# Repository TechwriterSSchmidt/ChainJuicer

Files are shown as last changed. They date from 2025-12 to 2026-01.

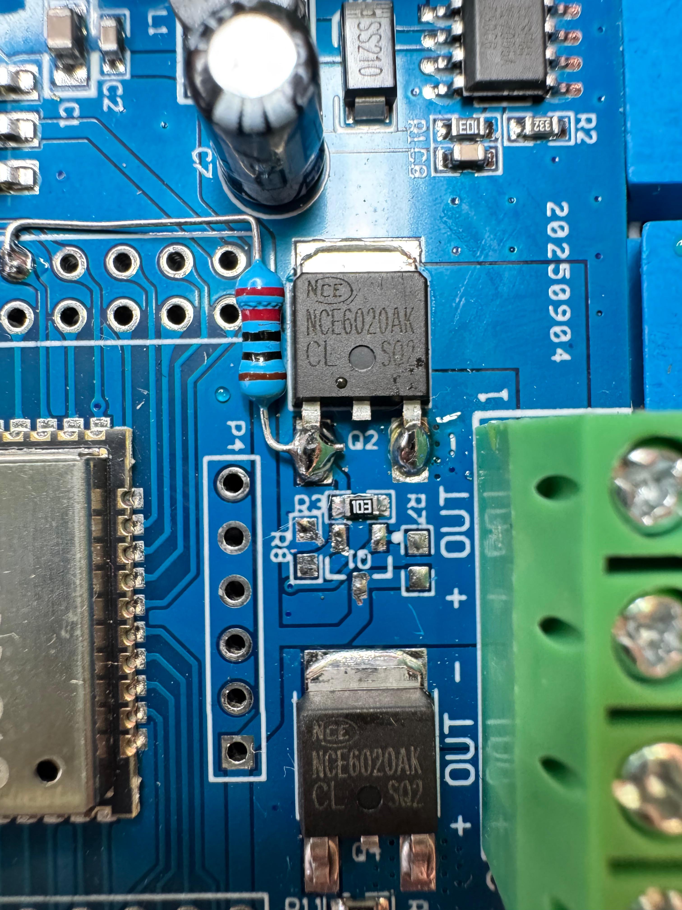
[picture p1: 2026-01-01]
pictures/Top view showing (or NOT showing) the desoldered transistor, R7 and R8.jpeg

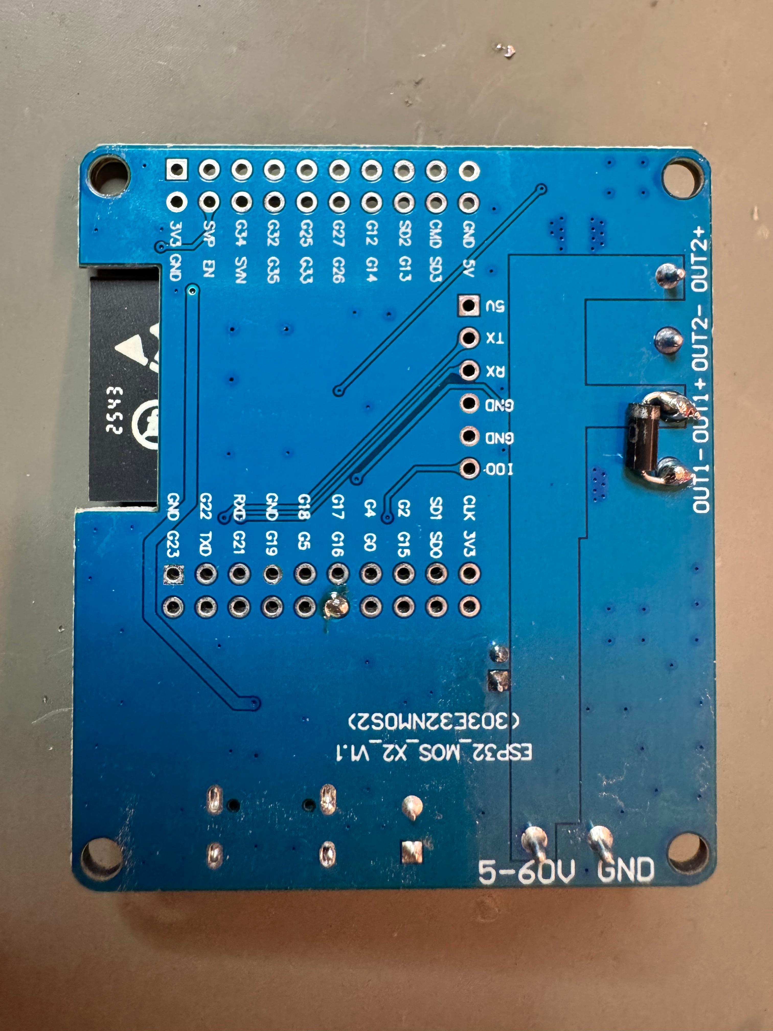
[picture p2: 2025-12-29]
pictures/Rear view showing the free-wheeling diode for the solenoid pump.jpeg

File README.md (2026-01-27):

# 🍋 Chain Juicer v2.0.0 (ESP32)

**The Swiss Army Knife for your Motorcycle Chain.**

An ESP32-based multi-tool featuring GPS-controlled chain lubrication, a Aux Power Manager for accessories, and an automated Heated Grips Controller. It combines intelligent maintenance with modern convenience and safety features like IMU-based crash detection.

**Easy to Build:** Designed around a widely available standard ESP32 Relay Board (LCTECH), this project requires **no custom PCB** and minimal soldering skills. It's the perfect entry point for DIY motorcycle electronics.

**Easy to Install:** No coding skills required! Use the [Web Installer](https://TechwriterSSchmidt.github.io/ChainJuicer/) to flash your ESP32 directly from the browser. Future updates can be done wirelessly via OTA (Over-The-Air) using the [latest firmware file](https://TechwriterSSchmidt.github.io/ChainJuicer/firmware.bin).

> **Note:** Version 2.0.0 introduces a new core architecture. For optimal stability and to prevent boot loops, please follow the **Recommended Pin Layout** below when building new hardware.

## Support my projects

If you like this project, consider a tip. Your tip motivates me to continue developing useful stuff for the DIY community. Thank you very much for your support!



## Recommended Pin Layout (Hardware v2.0)

For the most stable operation (avoiding "Boot Loops" and conflicts with internal ESP32 Strapping Pins), use the following connection scheme for new builds. 

| Component | ESP32 Pin (GPIO) | Notes |
| :--- | :--- | :--- |
| **PUMP (MOSFET)** | **GPIO 26** | Safe Output |
| **LED (WS2812B)** | **GPIO 32** | Standard |
| **BUTTON** | **GPIO 0** | Use Boot Button or external btn to GND |
| **TEMP (DS18B20)** | **GPIO 4** | **Important:** Requires 4.7kΩ Pull-Up Resistor. Do not use GPIO 2! |
| **GPS RX** | **GPIO 16 (RX2)** | Connect to GPS TX |
| **GPS TX** | **GPIO 27** | Connect to GPS RX |
| **IMU (SDA)** | **GPIO 21** | Standard Hardware I2C |
| **IMU (SCL)** | **GPIO 22** | Standard Hardware I2C |
| **SD Card (CS)** | **GPIO 5** | VSPI CS |
| **SD Card (CLK)** | **GPIO 18** | VSPI CLK |
| **SD Card (MISO)** | **GPIO 19** | VSPI MISO |
| **SD Card (MOSI)** | **GPIO 23** | VSPI MOSI |

> **Warning:** Avoid using **GPIO 12**, as it determines the flash voltage during boot (High = Boot Loop). Avoid **GPIO 2** for sensors with pull-ups for the same reason.

## Table of Contents
* [Features](#features)
* [Optional IMU Features](#optional-imu-features)
* [Optional SD Card Logging](#optional-sd-card-logging)
* [Hardware & Functionality Matrix](#hardware--functionality-matrix)
* [Automatic Temperature Compensation](#automatic-temperature-compensation)
* [Aux Port Manager](#aux-port-manager-gpio-17)
* [Data Logging (SPI Flash)](#data-logging-spi-flash)
* [Hardware](#hardware)
* [Operation](#operation)
* [Web Interface](#web-interface)
* [License](#license)
* [Installation](#installation)
* [BOM & Costs](#bom--costs-approx-2025)
* [Release Notes](RELEASE_NOTES.md)

## Features

| Feature | Description | Details |
| :--- | :--- | :--- |
| **Speed-Dependent Oiling** | 5 configurable speed ranges with individual intervals. | Intervals down to **0.1 km**. Pre-configured "Swiss Alpine Profile" (Base 5km, optimized for passes & highways). Default: 2 pulses/event. |
| **Smart Smoothing** | Linear interpolation & low-pass filter. | Avoids harsh jumps in lubrication intervals. |
| **Drift Filter** | Ignores GPS multipath reflections. | Prevents "ghost mileage" indoors/tunnels (HDOP > 5.0 or < 5 Sats). |
| **Safety Cutoff** | Hard limit for pump runtime. | Max 30s continuous run to prevent hardware damage. |
| **Start Delay** | Distance driven before first oiling. | Default **250 m**. Keeps garage floor clean. |
| **GPS Precision** | Exact distance measurement. | Uses TinyGPS++ library. |
| **Rain Mode** | Doubles oil amount in wet conditions. | **Button:** 1x Click. **Auto-Off:** 30 min or restart. LED: Blue Static. |
| **Chain Flush Mode** | Intensive oiling for cleaning/re-lubing. | **Button:** 4x Click. **Action:** Time-based (Configurable). LED: Cyan Blink (pulses while riding). |
| **Offroad Mode** | Time-based oiling for slow offroad riding. | **Button:** 3x Click. **Action:** Time-based (Pulses configurable). LED: Magenta Blink (pulses while riding). |
| **Emergency Mode** | Simulates speed if GPS fails. | **Auto:** After 3 min no signal (50 km/h sim). **Forced:** Manual activation. LED: Red Pulsing. |
| **WiFi & WebUI** | Configuration via Smartphone. | **Activation:** 5x Click. **Features:** OTA Update, LED config, Stats, Test functions. |
| **Night Mode** | Auto-dimming of LED. | **Default:** ON (20:00-06:00). Brightness: 5% (Dim) / 25% (Event). |
| **Bleeding Mode** | Continuous pumping for maintenance. | **WebUI:** "Start Bleeding Mode" Button. Fills oil line (25s). **Additive:** Trigger again to extend (max 75s). LED: Yellow Fast Blink. |
| **Tank Monitor** | Virtual oil level tracking. | **Default:** ON. Warns (Orange Fast Blink) when low (< Warning%). Red/Yellow Alt when empty. |
| **Aux Port Manager** | Smart control for accessories. | **Aux Power:** Auto-ON after boot (Delay). **Heated Grips:** Auto-PWM based on Speed/Temp/Rain. **Toggle:** Hold > 2s. |
| **Web Console** | Debugging without USB. | View live logs (GPS, Oiler, System) via WiFi on `/console`. |
| **Advanced Stats** | Usage analysis. | Usage % per speed range, total juice counts, odometer. |
| **Auto-Save** | Persistent storage. | Saves settings & odometer to NVS at standstill (< 7 km/h). |
| **Factory Reset** | Reset to defaults. | **WebUI:** Maintenance Page. |

## Optional IMU Features

By adding a **BNO085** (or BNO080) 9-Axis IMU, the system gains "Intelligence" and advanced safety features. The system automatically detects if the sensor is connected.

| Feature | Description | Benefit |
| :--- | :--- | :--- |
| **Garage Guard** | Detects if the bike is **Stationary** (Stability Check). | Prevents accidental oiling in the garage, even if the motor is running or GPS drifts. (5s stability check) |
| **Crash Detection** | Detects tip-overs (> 70° lean) or accidents. | Immediate safety cutoff for the pump. **Requires restart to reset.** |
| **Smart Stop** | Detects standstill via accelerometer before GPS reacts. | More precise oiling stops at traffic lights. **Visuals:** LED pulses Green (OK) or Red (Empty) when stopped. |
| **Telemetry Logger** | Records max lean angles (L/R), max acceleration, and braking G-forces. | Fun stats for the web interface ("How deep was I in that corner?"). |
| **Dynamic Intervals** | Analyzes riding style (Cruising vs. Racing). | Reduces oiling intervals during aggressive riding (high load on chain). |

*   **Calibration:** A dedicated Web Interface page allows zeroing the sensor. Includes a 5-second countdown and 3-second averaging for easy solo calibration.
*   **Logging:** All IMU data will be logged to the SD card (if active) for analysis.

## Optional SD Card Logging

For advanced users and data analysis, you can connect a standard **MicroSD Card Module** (SPI). The system automatically detects the card at boot and starts logging telemetry data.

*   **File Format:** CSV (Comma Separated Values)
*   **Interval:** 1 Second
*   **Files:** `log_X.csv` (Increments automatically)

### Wiring (VSPI Default)

| Pin | ESP32 GPIO |
| :--- | :--- |
| **CS** | GPIO 5 |
| **MOSI** | GPIO 23 |
| **MISO** | GPIO 19 |
| **CLK** | GPIO 18 |
| **VCC** | 5V |
| **GND** | GND |

### Logged Data

| Column | Description |
| :--- | :--- |
| **Type** | Event type (DATA = Periodic, EVENT = System Event) |
| **Time_ms** | System uptime in milliseconds |
| **Speed_GPS** | Raw GPS speed (km/h) |
| **Speed_Smooth** | Smoothed speed used for calculation (km/h) |
| **Odo_Total** | Total odometer reading (km) |
| **Dist_Accum** | Distance accumulated towards next oiling (km) |
| **Target_Int** | Current target interval (km) |
| **Pump_State** | 1 = Pump running, 0 = Idle |
| **Rain_Mode** | 1 = Active, 0 = Inactive |
| **Temp_C** | Current temperature (°C) |
| **Sats** | Number of satellites |
| **HDOP** | GPS Precision (Lower is better) |
| **Message** | System messages or debug info |
| **Flush_Mode** | 1 = Active, 0 = Inactive |

## Hardware & Functionality Matrix

This table shows which features are available depending on the connected hardware components.

| Feature | Basic Setup | + Temp Sensor | + IMU (MPU6050) | + SD Card |
| :--- | :---: | :---: | :---: | :---: |
| **Speed-Dependent Oiling** | ✅ | ✅ | ✅ | ✅ |
| **Rain Mode** | ✅ | ✅ | ✅ | ✅ |
| **Chain Flush Mode** | ✅ | ✅ | ✅ | ✅ |
| **Cross-Country Mode** | ✅ | ✅ | ✅ | ✅ |
| **Emergency Mode** | ✅ | ✅ | ✅ | ✅ |
| **Night Mode** | ✅ | ✅ | ✅ | ✅ |
| **Tank Monitor** | ✅ | ✅ | ✅ | ✅ |
| **Temp. Compensation** | ❌ | ✅ | ✅ | ✅ |
| **Turn Safety (Cornering)** | ❌ | ❌ | ✅ | ✅ |
| **Crash Detection** | ❌ | ❌ | ✅ | ✅ |
| **Garage Guard** | ❌ | ❌ | ✅ | ✅ |
| **Smart Stop** | ❌ | ❌ | ✅ | ✅ |
| **Aux Port: Aux Power** | ✅ | ✅ | ✅ | ✅ |
| **Aux Port: Heated Grips** | ❌ | ✅ | ✅ | ✅ |
| **Data Logging** | ❌ | ❌ | ❌ | ✅ |

*   **Basic Setup:** ESP32, GPS Module, Pump, Button, LED.
*   **Temp Sensor:** DS18B20 (OneWire).
*   **IMU:** BNO085 (I2C).
*   **SD Card / Flash:** SPI Flash / MicroSD for Logging.

## Automatic Temperature Compensation

This system uses a **DS18B20** temperature sensor to adjust the pump mechanics based on the viscosity of the oil.

**Why?**
Oil becomes thick like syrup in winter and thin like water in summer. Without compensation, the pump might fail to move cold oil or squirt too much hot oil.

**New Simplified Logic (Arrhenius):**
Instead of complex tables, the system uses the Arrhenius equation to model oil viscosity changes.

*   **Reference:** You set the optimal Pulse and Pause duration for **25°C** (Normal Temperature).
    *   *Recommendation:* Use a long pause (~2000ms) and adjust the pulse width. This ensures the pump always has enough time to refill, even with thick, cold oil.
*   **Oil Profile:** Select your oil type (Thin, Normal, Thick).
*   **Calculation:** The ESP32 automatically calculates the required energy for any temperature.
*   **Safety Limits:**
    *   **Minimum Pulse:** The system enforces a hard limit of **50ms** for the pulse duration to ensure the solenoid always moves, preventing "stuck" states at high temperatures.
*   **Update Interval:** Temperature is measured every 1 minute to ensure stable operation.

**Configuration:**
*   **Web Interface:** Simply enter your 25°C values and select the oil type.
*   **Sensor Detection:** If no sensor is connected, the system defaults to 25°C.

**Wiring:**
*   **VCC:** Board dependent (e.g. 5V-12V for Wide Range boards, or 3.3V/5V for standard)
*   **GND:** GND
*   **Data:** GPIO 4 - Requires 4.7kΩ Pull-Up Resistor to VCC.

## IMU Features (BNO085)

If an IMU is connected, the system enables advanced safety and convenience features:

*   **Turn Safety:** Prevents oiling while significant cornering.
    *   **Logic:** Oiling is paused if the bike leans > 20° towards the **tire side** (unsafe zone). Leaning towards the chain side is considered safe (oil drops on chain, not tire).
*   **Crash Detection:** Stops the pump immediately if the lean angle exceeds 70° (bike on ground).
*   **Garage Guard:** Detects if the bike is on the side stand or center stand and prevents oiling (even if GPS drifts).
*   **Smart Stop:** Uses accelerometer data to detect standstill faster than GPS.

## Aux Port Manager (GPIO 17)

The system features a versatile Auxiliary Output (MOSFET/Relay driver) that can be configured for two main purposes:

### 1. Aux Power (Switched Live)
Turns on your accessories (Navigation, USB, Lights) automatically when the ignition is ON.
*   **Logic:** Activates the output after a configurable delay when the ESP boots.
*   **Start Delay:** Configurable delay (default 15s) to protect the battery during engine cranking.
*   **Benefit:** No need to tap into the bike's wiring harness or ignition switch. Connect directly to the battery via the Chain Juicer.

### 2. Automated Heated Grips
Advanced PWM control for heated grips, far superior to simple "Low/High" switches.
*   **Hardware Recommendation:** [Coolride Heating Cartridges](https://www.coolride.de/Neue-Heizpatronen-Paar-einzeln-ohne-Schalter) (52W).
*   **Base Level:** Set your preferred minimum heat. **Default: 25%**.
*   **Speed Compensation:** Increases heat as you ride faster (Wind chill factor). **Default: 0.5x** (Medium).
*   **Temp Compensation:** Increases heat as it gets colder (requires Temp Sensor). **Default: 2.0x** (High).
*   **Start Temp:** Configurable threshold (**Default: 20°C**) below which the grips start working.
*   **Temp Offset:** Adjusts the sensor reading if placed near heat sources (e.g. engine).
*   **Rain Boost:** Automatically adds extra heat when Rain Mode is active. **Default: +10%**.
*   **Startup Boost:** Heats up quickly (**Default: 100% for 75s**) when you start the ride.
*   **Start Delay:** Configurable delay (**Default: 15s**) after boot before grips turn on to protect the battery.
*   **Reaction Speed:** Configurable smoothing (Slow/Medium/Fast) to determine how quickly the heat adjusts to speed changes.
    *   **Slow (Default):** ~10s smoothing. Very comfortable, filters out traffic lights.
    *   **Medium:** ~5s smoothing. Balanced.
    *   **Fast:** ~1s smoothing. Sporty response.

**Configuration:**
All parameters (Base %, Speed Factor, Temp Factor, Boosts, Delays, Reaction) are fully configurable via the new "Aux Config" web page.
**Default Mode:** The Aux Port is **OFF** by default and must be enabled in the Web Interface.

## Data Logging (SPI Flash)

For vibration-heavy environments or integrated builds, the system supports SPI Flash memory (simulated as SD card) for durable data logging.

**Recommended Hardware:**
*   **Adafruit SPI Flash SD Socket Adapter** (Product ID: 4899)
    *   *Why?* It acts like an SD card but is a soldered chip. Completely vibration-proof.
    *   *Capacity:* 512 MB (plenty for years of logs).

**Storage Capacity (512 MB Example):**
The system logs GPS tracks, speed, and events to `gps_log.csv`.

| Metric | Value |
| :--- | :--- |
| **Log Format** | CSV (Timestamp, Lat, Lon, Speed, Satellites, Alt) |
| **Data Rate** | 1 log entry per second (approx. 60 bytes) |
| **Storage per Hour** | ~216 KB |
| **Storage per 1000km** | ~3.6 MB (Avg. 60km/h) |
| **Total Capacity** | **> 140,000 km** of riding history |

**Data Retrieval:**
Since the chip is soldered, you cannot remove it.
*   **Web Download:** Use the "Maintenance" page in the Web Interface to download the full log file as `gps_log.csv`.

## Hardware

*   **MCU:** [LCTECH ESP32 Relay X1](http://www.chinalctech.com/cpzx/Programmer/Relay_Module/866.html).
    *   *Specs:* ESP32-WROOM-32E, Wide Range Input (7-30V), 2x Onboard MOSFET (**NCE6020AK**).
*   **GPS:** ATGM336H or NEO-6M (UART, 9600 Baud)
*   **Pump:** [12V Dosing Pump](https://de.aliexpress.com/item/1005010375479436.html).
    *   *Durability:* Tested with 2 pumps, each > 100,000 strokes without failure.
    *   *Tip:* Use my [Smart Pump Calibrator](https://github.com/TechwriterSSchmidt/Smart-Pump-Calibrator) to find the perfect settings for your pump.
*   **Temp Sensor:** DS18B20 (Waterproof)
*   **IMU (Optional):** BNO085 (or BNO080) for lean angle detection and standstill logic.
*   **LED:** WS2812B (NeoPixel) for status indication
*   **Button:** Normally Open against GND (Input Pullup)

### Pin Assignment (Current Config)

| Component | ESP32 Pin | Description |
| :--- | :--- | :--- |
| **Pump** | GPIO 26 | MOSFET Gate (Direct Drive) |
| **GPS RX** | GPIO 16 | Connected to GPS TX |
| **GPS TX** | GPIO 27 | Connected to GPS RX |
| **Button** | GPIO 0 | Switched against GND |
| **Boot Button** | GPIO 0 | Onboard Button (Parallel function) |
| **LED** | GPIO 32 | WS2812B Data In |
| **Temp Sensor** | GPIO 4 | DS18B20 Data (with 4k7 resistor between VCC and Data!) |
| **IMU SDA** | GPIO 21 | I2C Data |
| **IMU SCL** | GPIO 22 | I2C Clock |

*(Configurable in `include/config.h`)*

### MOSFET Wiring (Direct Drive)

To prevent the pump from triggering briefly during boot, desolder the little driver transistor of one output MOSFET (NCE6020AK) and connect the Gate of the MOSFET via a 220 Ohm resistor directly to the GPIO of the ESP. Add a Pull-Down resistor to stabilize the MOSFET. This modification may not be necessary for the Aux Port - your choice!

**Recommended Fuses:**
*   **Main Fuse (Battery):** 15A (Blue) - Protects the entire system.
*   **Aux Circuit (Grips):** 7.5A (Brown) - Protects the heated grips wiring (Load ~5.2A).
*   **Pump Circuit:** 5A (Tan) - Protects the pump and its MOSFET (Load ~4A Peak).

**Important:** The 220Ω series resistor and 10kΩ Pull-Down resistor are **mandatory** to prevent the pump from running uncontrollably during the ESP32 boot sequence.

```ascii
ESP32 GPIO (the one that switches the MOSFET
)  ----[ 200R ]----+-----> MOSFET Gate
                               |
                              [existing SMD pull-down resistor with 10k]
                               |
                              GND
```

*   **200R (Series):** Protects the ESP32 pin from current spikes (Gate capacitance).
*   **10k (Pull-Down):** Keeps the Gate at GND (0V) while the ESP32 is booting.

## Operation

### Button Functions

| Action | Duration | Condition | Function |
| :--- | :--- | :--- | :--- |
| **1x Click** | < 1s | Not in Emergency Mode | **Rain Mode** On/Off (LED: Blue). **Note:** Toggles with 600ms delay. |
| **3x Click** | < 2s | Always | **Offroad Mode** On/Off (LED: Magenta Blink). Time based oiling. |
| **4x Click** | < 2s | Always | **Chain Flush Mode** On/Off (LED: Cyan Blink). Time-based (Configurable). |
| **5x Click** | < 2s | Always | Activate **WiFi & Web Interface** (LED: White pulsing). |
| **Hold** | > 2s | Always | **Aux Port / Grip Heating** Manual Toggle (Override). |
| **Hold at Boot** | > 10s | During Power-On | **Factory Reset** (LED: Yellow -> Red fast blink) |

### Mode Hierarchy & Interactions

If multiple modes are active simultaneously, the system follows this priority logic:

| Priority | Mode | LED Indication | Interaction Notes |
| :--- | :--- | :--- | :--- |
| **1 (Highest)** | **Chain Flush** | **Cyan Blink** | Runs in parallel with Offroad Mode. Requires Speed > 7 km/h. |
| **2** | **Offroad** | **Magenta Blink** | Runs in parallel with Flush Mode. GPS speed is ignored; if IMU is present, oiling happens only when motion is detected. |
| **3** | **Emergency** | **Red Pulsing** | Active if GPS is lost. **Disables Rain Mode.** Note: Flush/Offroad will NOT oil because GPS speed is 0. |
| **4 (Lowest)** | **Rain** | **Blue** | Disabled by Emergency Mode. |

### LED Status Codes

| Color / Pattern | LED 1 (Main System) | LED 2 (Aux Port) |
| :--- | :--- | :--- |
| **Green** | Normal Operation (GPS Fix) | Aux Power: **ON** (12V Active) |
| **Blue** | Rain Mode Active | Heated Grips: **Level 1** (Low) |
| **Yellow** | Oiling Event (Breathing) / Bleeding Mode (Fast Blink) | Heated Grips: **Level 2** (Medium) |
| **Orange** | Tank Warning (2x Blink; pulses while riding) | Heated Grips: **Level 3** (High) |
| **Red** | Emergency Mode (Pulsing) | Heated Grips: **Level 4** (Max) |
| **Cycle** | - | Heated Grips: **Boost** (Blue->Red) |
| **Magenta** | No GPS (Solid) / Offroad (Blink; pulses while riding) | - |
| **Cyan** | Flush (Blink; pulses while riding) | - |
| **White** | WiFi Config Mode (Pulse) | - |
| **Red/Yellow** | Tank Empty (Alternating) | - |
| **Off** | - | Aux Port: **OFF** |

**Safety Note:** While riding, the system uses only **steady** or **pulsing** LED patterns to reduce distraction. Hard blinking is limited to standstill, maintenance, or warnings.

## Web Interface

Connect to the WiFi network (Default SSID: `ChainJuicer`, no password) after activating it. Open `192.168.4.1` in your browser.

**Adjustable Parameters:**
*   **Intervals:** Distance and pump pulses for 5 speed ranges.
*   **Modes:** Rain Mode, Emergency Mode (Force), Night Mode (Times & Brightness).
*   **LED:** Brightness for Day and Night (in %).
*   **Statistics:**
    *   **Usage %:** Driving profile analysis to optimize intervals.
    *   **Juices:** Counter for oilings per range.
    *   **Reset:** Reset stats or refill tank.

**Screenshots:** Check out the [web-ui examples](web-ui%20screenshots/)  folder to see what the interface looks like.

## Usage Scenarios & LED Status

The system uses two LEDs to communicate its status.
*   **LED 1 (Main):** System Status, Oiling, Warnings.
*   **LED 2 (Aux):** Status of the Auxiliary Port (Heated Grips / Aux Power).

| Scenario | Trigger / Action | LED 1 (Main) | LED 2 (Aux) | System Behavior |
| :--- | :--- | :--- | :--- | :--- |
| **Normal Ride** | GPS Fix, Speed > 7 km/h | **Green** | *State dependent* | System oils automatically based on speed and configured distance intervals. |
| **Oiling Event** | Distance reached | **Yellow Breathing** | *State dependent* | Pump releases oil pulse. |
| **Tunnel / Signal Loss** | No GPS signal > 3 min | **Red Pulsing** | *State dependent* | Enters **Auto Emergency Mode**. Assumes 50 km/h for oiling. Returns to Green when GPS is back. |
| **Rain Ride** | 1x Click | **Blue** | *State dependent* | **Rain Mode** active. Oiling amount is doubled (or interval halved). Auto-off after 30 min or restart. |
| **Aux Port: Manual Toggle** | Hold > 2s | *State dependent* | **Off / On** | Manually toggles the Aux Port (Override). |
| **Offroad / Enduro** | 3x Click | **Magenta Blink** | *State dependent* | **Offroad Mode** active. Oils based on time. If IMU is present, oiling happens only when motion is detected (GPS speed is ignored). |
| **Dust / Flushing** | 4x Click | **Cyan Blink** | *State dependent* | **Chain Flush Mode** active. Oils based on time (e.g. every 60s). Good for flushing dust or after cleaning. |
| **Configuration** | 5x Click | **White Pulse** | *State dependent* | Activates WiFi AP `ChainJuicer`. Open `192.168.4.1` to config. |
| **Tank Empty** | Reserve reached | **Red/Yellow Alternating** | *State dependent* | **Tank Empty**. Refill tank and reset counter via Web Interface. |
| **Aux Port: Aux Power** | Ignition ON (Delay) | *State dependent* | **Green** | Aux Port is ON (12V). Powers accessories like Dashcam/Navi. |
| **Aux Port: Heated Grips** | Auto-Control | *State dependent* | **Blue &rarr; Red** | **Blue:** Low Heat<br>**Yellow:** Medium Heat<br>**Orange:** High Heat<br>**Red:** Max Heat |
| **Hardware Debug** | Pump runs at boot | **Check Wiring!** | **Check Wiring!** | Ensure 10k Pull-Down resistor is installed between Gate and GND. |

## Technical Details

*   **Non-Blocking:** Pump control is asynchronous.
*   **Adaptive Smoothing:** Combination of Lookup Table and Low-Pass Filter.
*   **Smart Oiling (Hysteresis):** Start threshold at **95%**, trigger at **100%** (95% + 5% = 100%).
*   **Auto-Save:** The odometer is saved intelligently (at standstill < 7 km/h, but max. every 2 minutes).
*   **Timezone:** Automatic calculation of Central European Time (CET/CEST).

## Installation

### Option A: Web Installer (Recommended)
Flash the firmware directly from your browser (Chrome/Edge) without installing any software.
**[Open Web Installer](https://TechwriterSSchmidt.github.io/ChainJuicer/)**

### Option B: PlatformIO (For Developers)

**Important:** The recommended ESP32-32E board does **not** have a built-in USB-to-Serial converter. You need an external **USB-to-UART Adapter** (e.g., CP2102, CH340) to flash the initial firmware once. For updates, you can use the OTA page to upload new firmware via the webinterface.

*   **Connections:** TX->RX, RX->TX, GND->GND, 3.3V->3.3V (or 5V->5V).
*   **Boot Mode:** You might need to bridge GPIO0 to GND during power-up to enter bootloader mode.

1.  Clone or download the repository.
2.  Open in VS Code with installed **PlatformIO** Extension.
3.  Adjust Upload Port in `platformio.ini` if necessary.
4.  Compile and upload project (`Upload`).
5.  File system is not necessary (Data is saved in NVS/Preferences).

## BOM & Costs (approx. 2025)

The total project cost is very low compared to commercial alternatives (~150€+).

| Component | Description | Link (Example) | Approx. Price |
| :--- | :--- | :--- | :--- |
| **ESP32 Board** | LCTECH Relay X1 (NCE6020AK) | [Manufacturer](http://www.chinalctech.com/cpzx/Programmer/Relay_Module/866.html) | ~ 6.00 € |
| **GPS Module** | ATGM336H (Small & Fast) | [AliExpress](https://de.aliexpress.com/item/1005007759554488.html) | ~ 4.50 € |
| **Dosing Pump** | 12V Pulse Pump | [AliExpress](https://de.aliexpress.com/item/1005010375479436.html) | ~ 12.00 € |
| **Oil Tank** | 120cc RC Tank | [AliExpress](https://de.aliexpress.com/item/1588019770.html) | ~ 4.00 € |
| **Dosing Needle** | 14G Needle (100mm) | [AliExpress](https://de.aliexpress.com/item/1005010382140407.html) | ~ 2.00 € |
| **Luer Lock Adapter** | Adapter for Needle | [AliExpress](https://de.aliexpress.com/item/1005003777344843.html) | ~ 1.00 € |
| **TPU Hose** | 2m Oil/Fuel Line | [AliExpress](https://de.aliexpress.com/item/1005005390968147.html) | ~ 3.00 € |
| **Button** | Waterproof Button | [AliExpress](https://de.aliexpress.com/item/1005009185830140.html) | ~ 0.70 € |
| **LED** | WS2812B (Code supports up to 2x) | Generic | ~ 1.00 € |
| **Fuses** | KFZ-Flachsicherungen (15A, 7.5A, 5A) | Generic | ~ 2.00 € |
| **Small Parts** | Automotive Connectors (2x 2pin, 1x 4pin), Wires | Generic | ~ 13.00 € |
| **Housing** | 3D Printed (PETG/ASA) | DIY | ~ 2.00 € |
| **Flasher** | USB-to-UART Adapter (CP2102/CH340) | Generic | ~ 3.00 € |
| **Total (Basic)** | | | **~ 52.50 €** |
| | | | |
| **Temp Sensor (Optional)** | DS18B20 (Waterproof) | [AliExpress](https://de.aliexpress.com/item/1005006090368473.html) | ~ 1.50 € |
| **IMU (Optional)** | BNO085 (9-Axis) | [AliExpress](https://de.aliexpress.com/item/1005009898088463.html) | ~ 15.00 € |
| **SD Card (Optional)** | MicroSD SPI Module | [AliExpress](https://de.aliexpress.com/item/1005005302035188.html) | ~ 1.00 € |
| **Total (Full)** | | | **~ 70.00 €** |

*Note: Prices vary by shipping location and seller.*

### Hardware Notes
*   **LED:** The code is configured for **2x WS2812B LEDs**. You can use one for the Chain Juicer status display in the cockpit and a second one (optional) for the Aux Port (Grip Heating or Aux Power).
*   **LCTECH Board Modification (Critical):** If you are using the LCTECH Relay Board with the NCE6020AK MOSFET and J3Y driver circuit, you should modify the switching circuit of the pump (only the pump circuit!) to prevent the pump from triggering briefly during boot as follows:
    1.  **Remove:** Transistor `J3Y` (S8050) and Resistors `R8` & `R7`.
    2.  **Keep:** Resistor `R3` (10k Pull-Down).
    3.  **Add:** A **220 Ohm** resistor between GPIO 16 and the Gate of the MOSFET.
    *   *See `Docs/SCHEMATIC.txt` for details.*

## Disclaimer & Safety

**READ CAREFULLY BEFORE BUILDING OR USING THIS SYSTEM!**

*   **DIY Project:** This is a Do-It-Yourself project. You are solely responsible for the assembly, installation, and operation of the system.
*   **No Liability:** The author accepts **no liability** for any damage to your motorcycle, property, or person, nor for any accidents caused by the use or failure of this system.
*   **Oil on Tires:** Chain oilers involve liquids near moving parts. **Oil on the tire significantly reduces traction and can lead to crashes.**
    *   Ensure the dosing needle is positioned correctly so oil drips ONLY on the chain/sprocket, never on the tire or brake disc.
    *   Regularly check the system for leaks.
    *   **IMMEDIATELY clean any oil off the tire** if a spill occurs. Do not ride with oil on your tires.
*   **Road Safety:** Do not operate the configuration interface while riding. Focus on the road.

## License

This project is licensed under the **PolyForm Noncommercial License 1.0.0**.

- **Noncommercial Use**: You may use this software for personal, educational, or evaluation purposes.
- **Commercial Use Restricted**: You may NOT use this software for commercial purposes (selling, paid services, business use) without prior written consent.

<details>
<summary>View Full License Text</summary>

### PolyForm Noncommercial License 1.0.0

#### 1. Purpose
This license allows you to use the software for noncommercial purposes.

#### 2. Agreement
In order to receive this license, you must agree to its rules. The rules of this license are both obligations (like a contract) and conditions to your license. You must not do anything with this software that triggers a rule that you cannot or will not follow.

#### 3. License Grant
The licensor grants you a copyright license for the software to do everything you might do with the software that would otherwise infringe the licensor's copyright in it for any permitted purpose. However, you may only do so to the extent that such use does not violate the rules.

#### 4. Permitted Purpose
A purpose is a permitted purpose if it consists of:
1. Personal use
2. Evaluation of the software
3. Development of software using the software as a dependency or evaluation tool
4. Educational use

**Commercial use is strictly prohibited without prior written consent from the author.**

#### 5. Rules

##### 5.1. Noncommercial Use
You must not use the software for any commercial purpose. A commercial purpose includes, but is not limited to:
1. Using the software to provide a service to third parties for a fee.
2. Selling the software or a derivative work.
3. Using the software in a commercial environment or business workflow.

##### 5.2. Notices
You must ensure that anyone who gets a copy of any part of the software from you also gets a copy of these terms or the URL for them above, as well as copies of any copyright notice or other rights notice in the software.

#### 6. Disclaimer
**THE SOFTWARE IS PROVIDED "AS IS", WITHOUT WARRANTY OF ANY KIND, EXPRESS OR IMPLIED, INCLUDING BUT NOT LIMITED TO THE WARRANTIES OF MERCHANTABILITY, FITNESS FOR A PARTICULAR PURPOSE AND NONINFRINGEMENT.**

</details>

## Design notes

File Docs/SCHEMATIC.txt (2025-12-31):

=============================================================================
                     CHAINJUICER LIGHT - WIRING SCHEMATIC
=============================================================================

MCU: ESP32 DevKit V1 (or compatible)
Power Supply: 12V to 5V Step-Down Converter (e.g., LM2596) powering ESP32 via VIN

-----------------------------------------------------------------------------
[ POWER SUPPLY ]
-----------------------------------------------------------------------------
Battery (12V) (+) --------> [ Fuse 2A ] --------> [ DC-DC Converter IN+ ]
Battery (12V) (-) ------------------------------> [ DC-DC Converter IN- ]

[ DC-DC Converter OUT+ (5V) ] --> ESP32 VIN
[ DC-DC Converter OUT- (GND) ] -> ESP32 GND

-----------------------------------------------------------------------------
[ PUMP CONTROL (MOSFET) ]
-----------------------------------------------------------------------------
** IMPORTANT HARDWARE MODIFICATION FOR LCTECH BOARDS **
The default driver circuit on the LCTECH board uses a J3Y transistor that causes the pump to juice on every whenever the board is connected to power. In order to solve this, we need to modify the MOSFET circuit as follows:

1. REMOVE: Transistor J3Y (S8050)
2. REMOVE: Resistors R8 and R7
3. KEEP:   Resistor R3 (10k Pull-Down)
4. ADD:    220 Ohm Resistor between GPIO 16 and Gate of NCE6020AK MOSFET

Schematic after modification:
ESP32 GPIO 16 --[ 220 Ohm ]--> Gate (G) of NCE6020AK
                               |
                               [ R3 (10k) ] -> GND (Pull-Down)

MOSFET Drain (D) ---------> Pump (-)
MOSFET Source (S) --------> GND

Battery (12V) (+) --------> Pump (+)

* Note: Add a Flyback Diode (e.g., 1N4007) across Pump (+) and Pump (-)
  Cathode (Striped end) to (+)
  Anode to (-)

-----------------------------------------------------------------------------
[ GPS MODULE (e.g., BN-220 / ATGM336H) ]
-----------------------------------------------------------------------------
GPS VCC ------------------> ESP32 3.3V (or 5V depending on module)
GPS GND ------------------> ESP32 GND
GPS TX -------------------> ESP32 GPIO 27 (RX)
GPS RX -------------------> ESP32 GPIO 26 (TX)

-----------------------------------------------------------------------------
[ HANDLEBAR BUTTON ]
-----------------------------------------------------------------------------
Button Pin 1 -------------> ESP32 GPIO 4
Button Pin 2 -------------> GND

* Note: Internal Pull-Up is used in software.

-----------------------------------------------------------------------------
[ STATUS LED (WS2812B / NeoPixel) ]
-----------------------------------------------------------------------------
LED VCC ------------------> ESP32 5V (VIN) or 3.3V
LED GND ------------------> ESP32 GND
LED DIN ------------------> ESP32 GPIO 32

-----------------------------------------------------------------------------
[ TEMPERATURE SENSOR (DS18B20) ]
-----------------------------------------------------------------------------
Sensor VCC (Red) ---------> ESP32 3.3V
Sensor GND (Black) -------> ESP32 GND
Sensor Data (Yellow/White)> ESP32 GPIO 15

* Note: Requires a 4.7k Resistor between VCC and Data (Pull-Up).
  VCC ----[ 4.7k ]----+
                      |
  Data ---------------+

-----------------------------------------------------------------------------
[ AUX PORT (Heated Grips / Aux Power) ]
-----------------------------------------------------------------------------
ESP32 GPIO 17 ------------> Gate (G) of MOSFET (e.g., IRLZ44N)
                            |
                            [ 10k Resistor ] -> GND (Pull-Down)

MOSFET Drain (D) ---------> Grips (-) / Accessory (-)
MOSFET Source (S) --------> GND

Battery (12V) (+) --------> Grips (+) / Accessory (+)

* Note: For Heated Grips, ensure the MOSFET can handle the current (e.g. 5A).
  Heatsink recommended.

-----------------------------------------------------------------------------
[ SD CARD MODULE (Optional) ]
-----------------------------------------------------------------------------
SD VCC -------------------> ESP32 5V (VIN) or 3.3V
SD GND -------------------> ESP32 GND
SD CS --------------------> ESP32 GPIO 5
SD MOSI ------------------> ESP32 GPIO 23
SD MISO ------------------> ESP32 GPIO 19
SD SCK -------------------> ESP32 GPIO 18

=============================================================================
                               PIN SUMMARY
=============================================================================
GPIO 04  : Button (Input Pullup)
GPIO 05  : SD Card CS
GPIO 15  : DS18B20 Temp Sensor (Data)
GPIO 16  : Pump MOSFET (Output)
GPIO 17  : Aux Port (Heated Grips / Aux Power)
GPIO 18  : SD Card SCK
GPIO 19  : SD Card MISO
GPIO 23  : SD Card MOSI
GPIO 26  : GPS RX
GPIO 27  : GPS TX
GPIO 32  : WS2812B LED Data
=============================================================================

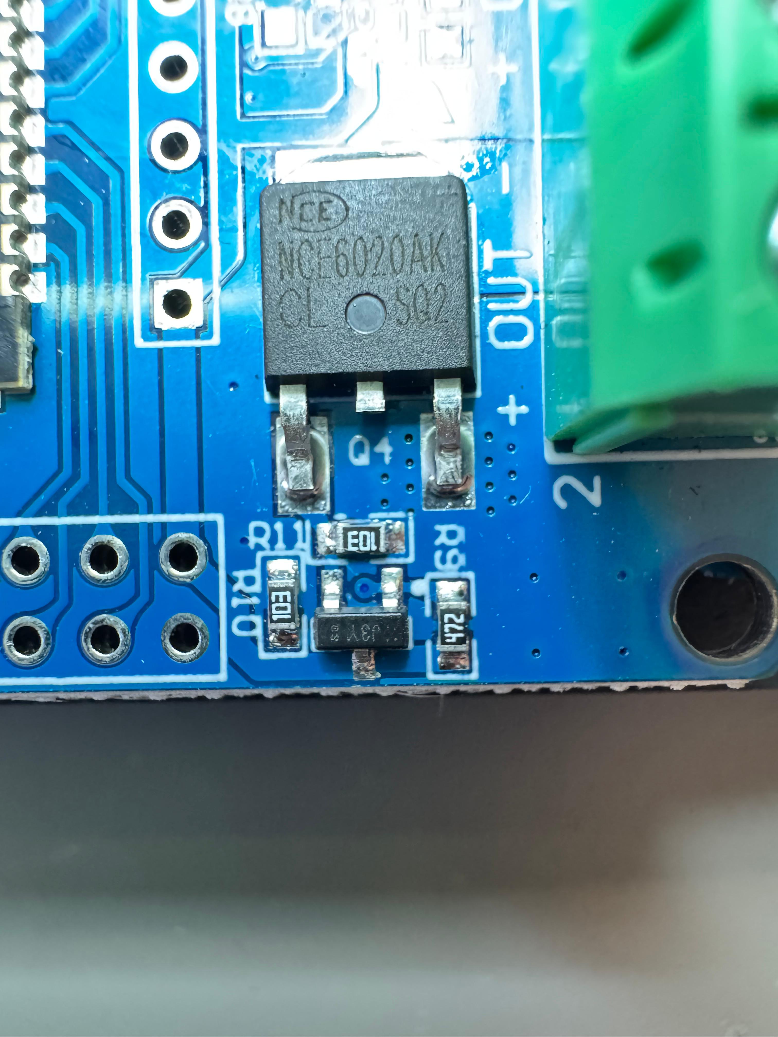
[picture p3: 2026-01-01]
pictures/Original circuit of the Aux Port MOSFET.jpeg

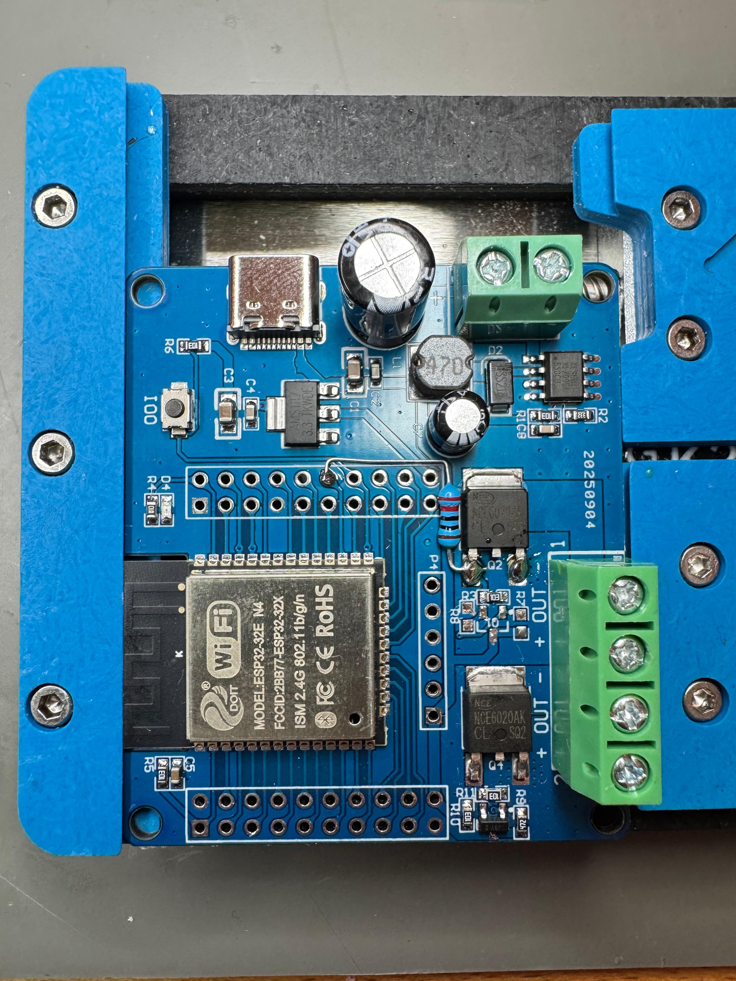
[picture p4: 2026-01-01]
pictures/Top view with 220R (GPIO16) connected to the GATE of the MOSFET.jpeg

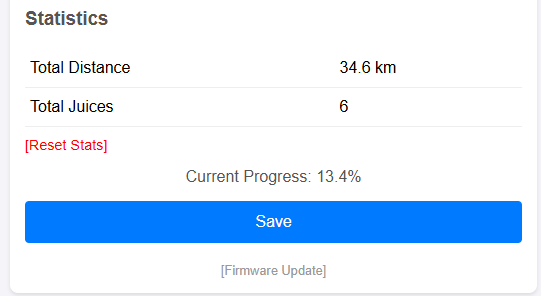
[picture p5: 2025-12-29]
web-ui screenshots/Config page - Statistics.png

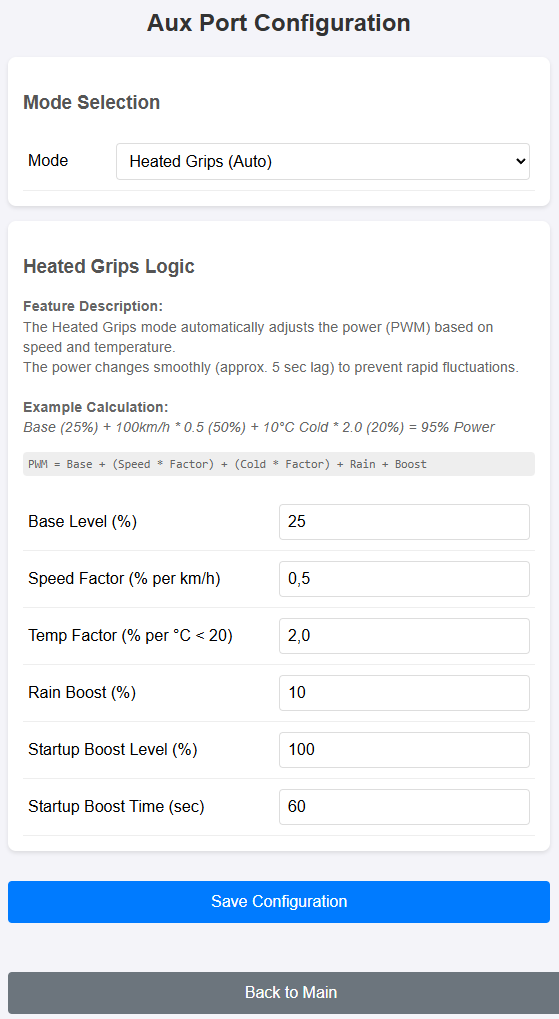
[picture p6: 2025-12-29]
web-ui screenshots/Aux Port Configuration (Heated Grips).png

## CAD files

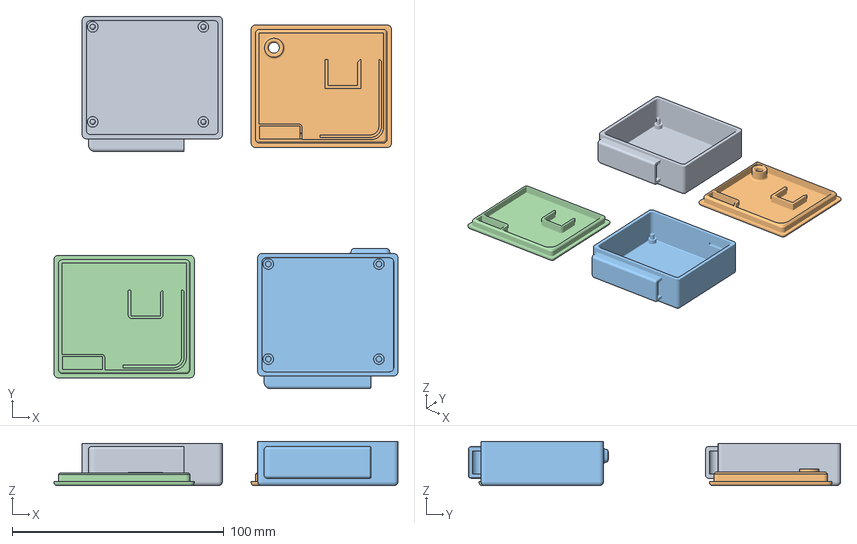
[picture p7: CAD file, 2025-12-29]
3d-print files/ChainOiler_housings.3mf
162.6 x 176.0 x 21.0 mm

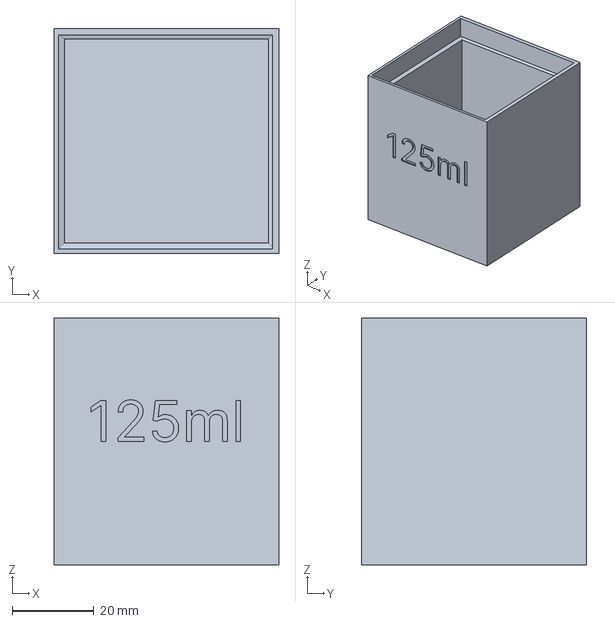
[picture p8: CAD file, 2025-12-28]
3d-print files/125ml measurement cube.3mf
55.0 x 55.0 x 60.5 mm

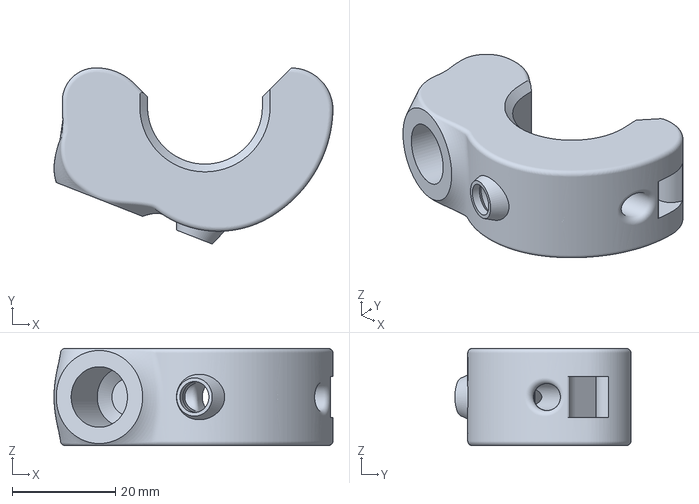
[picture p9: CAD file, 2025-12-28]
3d-print files/22mm handlebar housing for button 12mm and LED 5mm.3mf
54.0 x 34.1 x 18.8 mm

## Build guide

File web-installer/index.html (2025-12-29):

# 🍋 ChainJuicer

Connect your ESP32 via USB to your computer.
Click the button below to install the latest firmware.

Connect & Install

⚠️ Your browser does not support Web Serial.
Please use Google Chrome, Microsoft Edge, or Opera on Desktop or Android.

Make sure to close any other software using the serial port (e.g. VS Code, Cura).

Installer Version: 1.2
View on GitHub (https://github.com/TechwriterSSchmidt/ChainJuicer)

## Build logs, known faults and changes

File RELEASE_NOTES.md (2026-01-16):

# Release Notes

## v2.0.3 - Safety Hardening & Timezone Logic (2026-01-15)
*   **Safety & Reliability:**
    *   **Oiling Overflow Protection:** Implemented a cap (200%) on the oiling progress accumulator. This prevents a massive "backlog" of oiling pulses from building up during long sequences of corners (where oiling is paused for safety).
    *   **PWM Underflow Guard:** Added protection against integer underflow in the pump control logic, ensuring stability even with very short pulse durations.
*   **Timezone Logic:**
    *   **Configurable Offset:** Removed hardcoded Central Europe daylight saving rules in favor of a simple, robust UTC Offset setting. This cleans up the code and allows for global usage.

## v2.0.2 - Feature Update & Critical Fixes (2026-01-14)
*   **New Intuitive LED Colors:**
    *   **Green:** Normal (Ready).
    *   **Yellow (Flash):** Active Oiling Event (Pump Stroke).
    *   **Blue:** Rain Mode.
    *   **Amber/Orange:** Offroad Mode.
    *   **Cyan (Breathing):** GPS Searching.
    *   **Red (Pulsing):** Emergency Mode (No GPS / Forced).
    *   **Red/Yellow (Alternating):** Tank Empty!
    *   **Magenta (Blink):** Maintenance (Flush / Bleed).
*   **Enhanced WebConsole Logging:** Added detailed logging for every pump actuation, specifying the active mode (e.g., "normal-mode juicing started", "offroad-mode juicing started"). Flush Mode deactivation is now also logged.
*   **Offroad & Flush Improvements:**
    *   **Unified Speed Thresholds:** Set minimum speed activation threshold to 4.0 km/h for both Flush Mode and Offroad Mode.
    *   **Offroad Configuration:** Added "Pulses per Event" setting to Offroad Mode.
    *   **Immediate Action:** Flush Mode and Offroad Mode now trigger their first oiling event immediately upon activation.
*   **Critical Logic Fixes:**
    *   **Emergency Simulation Fix:** Fixed a bug where `currentSpeed` remained at 0 during Emergency Mode (GPS Simulation), enabling Flush/Offroad checks to pass even without real GPS.
    *   **Mode Transition:** Fixed stuck "Searching" state after Flush/Bleeding/Offroad modes ended.
    *   **Emergency Handover:** Emergency Mode (Forced) no longer auto-disables Offroad Mode (allowing manual timer-based oiling usage).
*   **Stability:** Fixed compilation errors in LED logic and various state machine refinements.

## v2.0.1 - Bleeding Timing Fix (2026-01-06)
*   **Bleeding Mode:** Fixed a millis underflow race that made the pump run at ~6 Hz despite 60/320 ms settings. Bleeding now uses a simple hard-coded scheduler (pulse 60 ms, pause 320 ms) with an underflow guard. Logging noise was reduced for the web/serial console.

## v2.0.0 - Core Refactoring & Smart Stop (2026-01-05)

This update introduces significant architectural changes to support future platforms (HelLo Juicer) while enhancing the current user experience.

### Core Architecture
*   **Multi-Platform Support:** Refactored the core logic (`Oiler`, `AuxManager`) to be platform-agnostic.
    *   Decoupled storage logic using a new `IPersistence` interface, allowing the same core code to run on ESP32 (using NVS) and nRF52 (using FileSystem).
    *   Abstracted hardware pin definitions from the core library.
*   **ESP32 Compatibility:** Updated the codebase to support **ESP32 Arduino Core 3.x**.
    *   Migrated PWM generation from the deprecated `ledcSetup`/`ledcAttachPin` to the new `ledcAttach` API.
    *   Updated Watchdog Timer (WDT) initialization to the new configuration structure.

## v1.1.2 - IMU Calibration Update + Smart Stop Mode Enhancement (2026-01-04)

Improved the IMU calibration process for better usability and accuracy, especially for solo riders.

*   **Non-Blocking Calibration:** The calibration process no longer freezes the web interface.
*   **Countdown Timer:** Added a 5-second countdown before calibration starts, giving the rider time to stabilize the bike (hands on handlebars).
*   **Averaging:** Calibration now averages sensor data over 3 seconds (instead of a single snapshot) to filter out rider movement and vibrations.
*   **Visual Feedback:** The Web Interface automatically redirects to the Serial Console to display the countdown and calibration status in real-time.
*   
*   ### User Experience (Smart Stop)
Enhanced the visual feedback when the motorcycle is stationary (e.g., at traffic lights) to provide useful status information without distraction.

*   **Smart Stop Mode:** When the bike is stopped (< 3 km/h), the LED switches to a "Pulsing" mode to distinguish it from normal operation.
    *   **Green Pulsing:** System OK.
    *   **Blue Pulsing:** Rain Mode Active.
    *   **Orange Blinking (2x):** Tank Low (Warning Level).
    *   **Red Pulsing:** Tank Empty.
*   **Tank Warning Logic:** The "Smart Stop" mode now correctly respects the user-configured tank warning threshold instead of a fixed value.

## v1.1.1 - Stability & Robustness (2026-01-03)

This patch focuses on system reliability and failsafe mechanisms to ensure the ChainJuicer operates autonomously without hanging, even in case of hardware glitches.

*   **Watchdog Timer (WDT):** Added a system watchdog that automatically resets the ESP32 if the main loop freezes for more than 5 seconds. This prevents the system from hanging indefinitely due to software bugs or electrical interference.
*   **I2C Bus Recovery:** Implemented a recovery sequence for the IMU connection. If the BNO085 sensor locks up the I2C bus (e.g., due to voltage spikes), the system attempts to clear the bus by toggling the clock line before giving up.
*   **Robust Initialization:** Improved the startup sequence to handle missing or malfunctioning sensors gracefully without blocking the rest of the system.

## v1.1.0 - UI & UX Refinement (Released)

This update focuses on streamlining the user experience, cleaning up the Web Interface, and refining system feedback.

### Web Interface Overhaul
*   **New Maintenance Page:** Created a dedicated area for system tools to declutter the main settings page.
    *   **Visual Safety:** "Bleeding Mode" is color-coded yellow (Warning), "Factory Reset" is red (Danger), while "Firmware Update" and "Restart System" are gray (Neutral).
    *   **Functionality:** Includes Pump Test, Bleeding Mode, IMU Configuration, Serial Console, Firmware Update, and System Restart.
*   **Heated Grips Settings:** Reorganized the settings page. Parameters are now logically grouped (Compensation factors vs. Base settings) with visual separation for better usability.
*   **Factory Reset:** Removed the hardware-based Factory Reset (Hold > 10s) to prevent accidental resets. Factory Reset is now exclusively available via the Web Interface.
*   **Layout Improvements:** Moved the "Statistics" card to the top of the Settings page for immediate visibility of key metrics.

### UX & Feedback
*   **Heated Grips Boost:** The LED now cycles through colors (Blue &rarr; Red) during the startup boost phase, providing a more intuitive "heating up" visualization.
*   **Heated Grips Reaction Speed:** Added a configurable "Reaction Speed" setting (Slow/Medium/Fast) to control how quickly the heating adjusts to speed changes. "Slow" (default) provides a very smooth, high-end feel.
*   **Button Logic:** Consolidated button commands for a simplified control scheme.
*   **WiFi Safety:** The 5-click WiFi command now only activates WiFi or extends the timer. It prevents accidental deactivation via button (deactivation is handled automatically by timeout or driving).
*   **Documentation:** Added a clear "Mode Hierarchy" section to the manual, explaining how Chain Flush, Offroad, Emergency, and Rain modes interact.

### Logic Improvements
*   **Aux Port Persistence:** The ON/OFF state of the Aux Port (Heated Grips / Power) is now saved to non-volatile memory. The system remembers if you turned it off manually and restores the state after a reboot.
*   **Heated Grips Startup:** Fixed the startup logic. The "Startup Boost" now correctly begins *after* the configured "Start Delay" has elapsed, ensuring the boost phase isn't consumed while waiting for the engine to stabilize.
*   **Temperature Compensation:** Changed from hysteresis-based to a fixed 15-minute update interval for more stable and predictable viscosity adjustments.
*   **IMU Turn Safety:** Corrected the logic to suppress oiling when leaning towards the **tire** (unsafe side). When leaning towards the chain, oiling is now permitted.
*   **Console Logging:** Added comprehensive logging of all physical button presses and WebUI actions to the Web Console for better diagnostics.
*   **Bleeding Stats:** Fixed an issue where oil consumption during Bleeding Mode was not logged. The total amount consumed is now displayed in the console upon completion.
*   **Persistent Emergency Mode:** The "Forced Emergency Mode" setting is now saved to non-volatile memory. This allows the mode to persist across system restarts, which is critical for long trips with a broken GPS module.
*   **System Tools Feedback:** Fixed "Restart System" and "Factory Reset" buttons. They now require a **3x click confirmation** to prevent accidental activation. The buttons display a countdown (e.g., "1/3") and are reordered for better safety.
*   **Additive Bleeding Mode:** The Bleeding Mode can now be extended by triggering it again while active. Each trigger adds 20 seconds to the duration (up to a maximum of 60 seconds / 3x). This allows for easier priming of long oil lines without restarting the process repeatedly.
*   **Pump Noise Reduction:** Optimized the PWM ramp-up/ramp-down logic to start at ~50% duty cycle. This eliminates the motor "whining" sound at low power levels where torque is insufficient to move the pump.
*   **UI Visibility:** Updated the "Home" button arrow in the Web Interface to a bold `<` symbol for better rendering on iOS devices.
*   **Bleeding Feedback:** Added a live countdown timer to the Serial Console during Bleeding Mode (e.g., "Bleeding... 15s").
*   **Heated Grips Boost Logic:** Improved the startup boost logic. The boost timer now resets correctly when the grips are manually enabled during a ride, ensuring the "quick heat" feature works every time they are switched on, not just at boot.
*   **Garage Guard Logic:** Replaced the complex lean-angle based "Parked" detection with a robust "Stability Check". The system now detects if the bike is stationary (variance check) for 5 seconds, regardless of lean angle (Side Stand vs. Center Stand).

## v1.0.0 - Initial Release (2025-12-29)

**Chain Juicer** is a multi-tool for motorcycle chain maintenance. This initial release brings a complete suite of features for intelligent chain lubrication and accessory management, designed for the ESP32 platform.

### Key Features

*   **Speed-Dependent Oiling:** 5 configurable speed ranges with individual intervals (down to 0.1 km). Includes the pre-configured "Swiss Alpine Profile".
*   **Smart Smoothing:** Linear interpolation and low-pass filtering for smooth operation.
*   **GPS Precision:** Accurate distance measurement with a **Drift Filter** to ignore multipath reflections (tunnels/indoors).
*   **Rain Mode:** One-click activation to double the oil amount. Auto-off after 30 minutes or reboot.
*   **Chain Flush Mode:** Intensive, time-based oiling for cleaning the chain or post-rain maintenance.
*   **Offroad Mode:** Time-based oiling intervals for slow, technical riding where distance is minimal.
*   **Emergency Mode:** Automatic fallback to simulated speed (50 km/h) if GPS signal is lost for > 3 minutes.
*   **Temperature Compensation:** Automatically adjusts pump pulse duration based on ambient temperature and selected oil viscosity profile (Thin, Normal, Thick).

### Aux Port Manager

*   **Heated Grips Control:** Automated PWM control based on speed (wind chill), temperature, and rain status. Includes a "Boost" mode for rapid heating.
*   **Aux Power:** Switched 12V output with configurable start delay to protect the battery during cranking.

### Web Interface & Connectivity

*   **Responsive WebUI:** Dark mode interface for configuration, statistics, and monitoring.
*   **WiFi Management:** WiFi is off by default to save power; activated via button sequence (5x click). Auto-off when driving.
*   **Maintenance Page:** Dedicated tools for pump testing, system bleeding, and factory reset.
*   **OTA Updates:** Wireless firmware updates directly from the browser.
*   **Web Console:** Live serial logging via the web interface for debugging without USB.

### Safety & Monitoring

*   **Tank Monitor:** Virtual oil level tracking with LED warning (Red 2x blink) when low.
*   **Safety Cutoff:** Hard limit on pump runtime to prevent hardware damage.
*   **IMU Integration (Optional):**
    *   **Garage Guard:** Prevents oiling when parked on the side stand (> 10° lean).
    *   **Crash Detection:** Stops the pump immediately if a tip-over (> 70° lean) is detected.
    *   **Smart Stop:** Detects standstill via accelerometer for faster response than GPS.

### Logging

*   **Statistics:** Tracks total distance, pump cycles, and usage percentage per speed range.
*   **SD Card Logging (Optional):** Records detailed telemetry (Speed, GPS, IMU, Pump State) to CSV files for analysis.

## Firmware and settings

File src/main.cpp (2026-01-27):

#include <Arduino.h>
#include <WiFi.h>
#include <WebServer.h>
#include <DNSServer.h>
#include <TinyGPS++.h>
#include <esp_task_wdt.h>
#include <esp_system.h>
#include <Update.h>
#include <Preferences.h>
#include "config.h"
#include "Oiler.h"
#include "AuxManager.h"
#include "html_pages.h"
#include "WebConsole.h"
#include "EspPersistence.h"

#ifdef SD_LOGGING_ACTIVE
    #include "FS.h"
    #include "SD.h"
    #include "SPI.h"
#endif

// Watchdog Timeout in seconds
#define WDT_TIMEOUT 8

// Global Objects
TinyGPSPlus gps;
HardwareSerial gpsSerial(2); // UART2
WebServer server(80);
DNSServer dnsServer;
EspPersistence persistence;
Oiler oiler(&persistence, PUMP_PIN, LED_PIN, TEMP_SENSOR_PIN);
AuxManager auxManager(&persistence);

#ifdef SD_LOGGING_ACTIVE
    File logFile;
    String currentLogFileName = "";
    unsigned long lastLogTime = 0;
    bool sdInitialized = false;
#endif

// WiFi Timer Variables
unsigned long wifiStartTime = 0;
bool wifiActive = false; // Default OFF
const unsigned long WIFI_TIMEOUT = WIFI_TIMEOUT_MS;

// Restart / Reset Flags
volatile bool shouldRestart = false;
volatile bool shouldFactoryReset = false;
unsigned long restartTimer = 0;

String getZurichTime() {
    if (!gps.time.isValid() || !gps.date.isValid()) return "--:--";
    
    int year = gps.date.year();
    int month = gps.date.month();
    int day = gps.date.day();
    int hour = gps.time.hour();
    int minute = gps.time.minute();
    
    // Use Oiler's centralized logic
    int localHour = oiler.calculateLocalHour(hour, day, month, year);
    
    // Calculate offset for display string (UTC+1 or +2)
    int diff = localHour - hour;
    if (diff < 0) diff += 24;
    
    char buf[32];
    sprintf(buf, "%02d:%02d (UTC+%d)", localHour, minute, diff);
    return String(buf);
}

void resetWifiTimer() {
    wifiStartTime = millis();
}

void handleCss() {
    server.sendHeader("Cache-Control", "public, max-age=86400");
    server.send(200, "text/css", htmlCss);
}

void handleHelp() {
    resetWifiTimer();
    String html = htmlHelp;
    html.replace("%VERSION%", FIRMWARE_VERSION);
    server.send(200, "text/html", html);
}

void handleResetStats() {
    resetWifiTimer();
#ifdef GPS_DEBUG
    Serial.println("CMD: Reset Stats");
#endif
    webConsole.log("CMD: Reset Stats");
    oiler.resetStats();
    server.sendHeader("Location", "/settings");
    server.send(303);
}

void handleResetTimeStats() {
    resetWifiTimer();
#ifdef GPS_DEBUG
    Serial.println("CMD: Reset Time Stats");
#endif
    webConsole.log("CMD: Reset Time Stats");
    oiler.resetTimeStats();
    server.sendHeader("Location", "/settings");
    server.send(303);
}

void handleRefill() {
    resetWifiTimer();
#ifdef GPS_DEBUG
    Serial.println("CMD: Refill Tank");
#endif
    webConsole.log("CMD: Refill Tank");
    oiler.resetTankToFull();
    server.sendHeader("Location", "/");
    server.send(303);
}

void handleToggleEmerg() {
    resetWifiTimer();
    bool current = oiler.isEmergencyModeForced();
    oiler.setEmergencyModeForced(!current);
    webConsole.log("CMD: Toggle Emergency Mode " + String(!current ? "ON" : "OFF"));
    oiler.saveConfig();
    server.sendHeader("Location", "/");
    server.send(303);
}

void handleUpdate() {
    resetWifiTimer();
    server.send(200, "text/html", htmlUpdate);
}

void handleUpdateResult() {
    resetWifiTimer();
    server.sendHeader("Connection", "close");
    if (Update.hasError()) {
        server.send(200, "text/plain", "Update Failed. Please try again.");
        oiler.setUpdateMode(false);
    } else {
        server.send(200, "text/html", "<html><head><meta http-equiv='refresh' content='10;url=/'></head><body><h2>Update Success!</h2><p>Rebooting system...</p></body></html>");
        delay(1000);
        ESP.restart();
    }
}

void handleUpdateProcess() {
    resetWifiTimer();
    esp_task_wdt_reset(); // Feed the dog during update!
    oiler.setUpdateMode(true); // Enable LED indication
    HTTPUpload& upload = server.upload();
    if (upload.status == UPLOAD_FILE_START) {
        Serial.printf("Update: %s\n", upload.filename.c_str());
        webConsole.logf("Update Start: %s", upload.filename.c_str());
        if (!Update.begin(UPDATE_SIZE_UNKNOWN)) { //start with max available size
            Update.printError(Serial);
            webConsole.log("Update Begin Error");
        }
    } else if (upload.status == UPLOAD_FILE_WRITE) {
        /* flashing firmware to ESP*/
        if (Update.write(upload.buf, upload.currentSize) != upload.currentSize) {
            Update.printError(Serial);
        }
    } else if (upload.status == UPLOAD_FILE_END) {
        if (Update.end(true)) { //true to set the size to the current progress
            Serial.printf("Update Success: %u\nRebooting...\n", upload.totalSize);
            webConsole.logf("Update Success: %u bytes", upload.totalSize);
        } else {
            Update.printError(Serial);
            webConsole.log("Update End Error");
        }
    }
}

#ifdef SD_LOGGING_ACTIVE
void initSD() {
    SPI.begin(SD_CLK_PIN, SD_MISO_PIN, SD_MOSI_PIN, SD_CS_PIN);
    if (!SD.begin(SD_CS_PIN)) {
        Serial.println("SD Card Mount Failed");
        return;
    }
    
    uint8_t cardType = SD.cardType();
    if (cardType == CARD_NONE) {
        Serial.println("No SD card attached");
        return;
    }

    // Use single log file for easy download
    currentLogFileName = "/gps_log.csv";
    Serial.print("Logging to: ");
    Serial.println(currentLogFileName);

    bool needHeader = !SD.exists(currentLogFileName);
    logFile = SD.open(currentLogFileName, FILE_WRITE);
    if (logFile) {
        // Write Header
        if (needHeader) {
            logFile.println("Type,Time_ms,Speed_GPS,Speed_Smooth,Odo_Total,Dist_Accum,Target_Int,Pump_State,Rain_Mode,Temp_C,Sats,HDOP,Message,Flush_Mode,Offroad_Mode,Bleeding_Mode,Emerg_Mode,Progress,Blocked_Reason");
        }
        
        // Dump Config
        logFile.println("EVENT,0,,,,,,,,,,SESSION START");
        logFile.println("EVENT,0,,,,,,,,,,CONFIG DUMP START");
        logFile.printf("EVENT,0,,,,,,,,,,Rain Multiplier: %d\n", (oiler.isRainMode() ? 2 : 1));
        for(int i=0; i<5; i++) {
            SpeedRange* r = oiler.getRangeConfig(i);
            if(r) {
                logFile.printf("EVENT,0,,,,,,,,,,Range %d: >%.1f km/h -> %.1f km\n", 
                    i, r->minSpeed, r->intervalKm);
            }
        }
        
        // Log Boot Reason
        esp_reset_reason_t reason = esp_reset_reason();
        logFile.printf("EVENT,%lu,,,,,,,,,,Boot Reason: %d\n", millis(), reason);
        
        logFile.close();
        sdInitialized = true;
    } else {
        Serial.println("Failed to open log file for writing");
    }
}

void writeLogLine(String type, String message = "") {
    if (!sdInitialized) return;

    File f = SD.open(currentLogFileName, FILE_APPEND);
    if (f) {
        f.printf("%s,%lu,%.2f,%.2f,%.2f,%.2f,%.2f,%d,%d,%.1f,%d,%.2f,%s,%d,%d,%.2f,%s\n",
            type.c_str(),
            millis(),
            gps.speed.kmph(),
            oiler.getSmoothedSpeed(),
            oiler.getOdometer(),
            oiler.getCurrentDistAccumulator(),
            oiler.getCurrentTargetDistance(),
            oiler.isPumpRunning(),
            oiler.isRainMode(),
            oiler.getCurrentTempC(),
            gps.satellites.value(),
            gps.hdop.hdop(),
            message.c_str(),
            oiler.isFlushMode(),
            oiler.offroadMode, // Status
            oiler.isBleedingMode(), // Bleeding
            oiler.isEmergencyMode(), // Emergency
            oiler.getCurrentProgress(), // Progress
            oiler.getBlockedReason().c_str() // Blocked Reason
        );
        f.close();
    }
}
#endif

void handleSettings() {
    resetWifiTimer();
#ifdef GPS_DEBUG
    Serial.println("Serving Settings Page"); 
#endif
    String html = htmlHeader;
    html.replace("%TIME%", getZurichTime());
    html.replace("%SATS%", String(gps.satellites.value()));
    
    String tempHeader = "--";
    if (oiler.isTempSensorConnected()) {
        tempHeader = String(oiler.getCurrentTempC(), 1);
    }
    html.replace("%TEMP%", tempHeader);

    double totalRecentTime = oiler.getRecentTotalTime();

    for(int i=0; i<NUM_RANGES; i++) {
        SpeedRange* r = oiler.getRangeConfig(i);
        
        // Calculate percentage
        float pct = 0.0;
        if (totalRecentTime > 0) {
             pct = (oiler.getRecentTimeSeconds(i) / totalRecentTime) * 100.0;
        }

        html += "<tr><td>";
        html += String((int)r->minSpeed) + "-" + String((int)r->maxSpeed) + " km/h";
        html += "</td><td><input type='number' step='0.1' name='km" + String(i) + "' value='" + String(r->intervalKm) + "' class='km-input'>";
        html += "</td><td style='text-align:center;color:#fff'>" + String(pct, 1) + "%";
        html += "</td><td style='text-align:center;color:#fff'>" + String(oiler.getRecentOilingCount(i));
        html += "</td><td><input type='number' name='p" + String(i) + "' value='" + String(r->pulses) + "' class='pulse-input'></td></tr>";
    }
    
    // Add Reset Link below the table
    html += "</table><div style='text-align:left;margin-top:10px;margin-bottom:10px'><a href='/reset_time_stats' style='color:red;text-decoration:none;font-size:1.1em'>[Reset Stats]</a></div>";
    
    String footer = htmlFooter;
    
    // Remove "</table>" from the start of htmlFooter since we already closed the table above
    if (footer.startsWith("</table>")) {
        footer = footer.substring(8); // Remove </table>
    }
    
    // Temperature Compensation Injection
    bool sensorConnected = oiler.isTempSensorConnected();
    
    footer.replace("%TC_PULSE%", String((int)oiler.tempConfig.basePulse25));
    footer.replace("%TC_PAUSE%", String((int)oiler.tempConfig.basePause25));
    
    footer.replace("%OIL_THIN%", (oiler.tempConfig.oilType == Oiler::OIL_THIN) ? "checked" : "");
    footer.replace("%OIL_NORMAL%", (oiler.tempConfig.oilType == Oiler::OIL_NORMAL) ? "checked" : "");
    footer.replace("%OIL_THICK%", (oiler.tempConfig.oilType == Oiler::OIL_THICK) ? "checked" : "");
    
    footer.replace("%TEMP_C%", String(oiler.getCurrentTempC(), 1));

    footer.replace("%PROGRESS%", String(oiler.getCurrentProgress() * 100.0, 1));
    
    // Convert 0-255 to 0-100% for Display
    footer.replace("%LED_DIM%", String(map(oiler.ledBrightnessDim, 2, 202, 0, 100)));
    footer.replace("%LED_HIGH%", String(map(oiler.ledBrightnessHigh, 2, 202, 0, 100)));
    
    footer.replace("%EMERG_CHECKED%", oiler.isEmergencyModeForced() ? "checked" : "");
    footer.replace("%START_DLY%", String(oiler.startupDelayMeters, 0));
    footer.replace("%OFFROAD_INT%", String(oiler.offroadIntervalMin));
    footer.replace("%OFFROAD_PLS%", String(oiler.offroadPulses));
    
    footer.replace("%FLUSH_EV%", String(oiler.flushConfigEvents));
    footer.replace("%FLUSH_PLS%", String(oiler.flushConfigPulses));
    footer.replace("%FLUSH_INT%", String(oiler.flushConfigIntervalSec));
    
    footer.replace("%TANK_CHECKED%", oiler.tankMonitorEnabled ? "checked" : "");
    footer.replace("%TANK_CAP%", String(oiler.tankCapacityMl, 0));
    footer.replace("%DROP_ML%", String(oiler.dropsPerMl));
    footer.replace("%DROP_PLS%", String(oiler.dropsPerPulse));
    footer.replace("%TANK_WARN%", String(oiler.tankWarningThresholdPercent));
    footer.replace("%TANK_LEVEL%", String(oiler.currentTankLevelMl, 1));
    float pct = (oiler.tankCapacityMl > 0) ? (oiler.currentTankLevelMl / oiler.tankCapacityMl) * 100.0 : 0.0;
    footer.replace("%TANK_PCT%", String(pct, 0));

    footer.replace("%TOTAL_DIST%", String(oiler.getTotalDistance(), 1));
    footer.replace("%PUMP_COUNT%", String(oiler.getPumpCycles()));

    html += footer;
    
    server.send(200, "text/html", html);
}

void handleLEDSettings() {
    resetWifiTimer();
    String html = htmlLEDSettings;
    
    html.replace("%LED_DIM%", String(map(oiler.ledBrightnessDim, 2, 202, 0, 100)));
    html.replace("%LED_HIGH%", String(map(oiler.ledBrightnessHigh, 2, 202, 0, 100)));
    
    html.replace("%NIGHT_CHECKED%", oiler.nightModeEnabled ? "checked" : "");
    html.replace("%NIGHT_START%", String(oiler.nightStartHour));
    html.replace("%NIGHT_END%", String(oiler.nightEndHour));
    html.replace("%NIGHT_BRI%", String(map(oiler.nightBrightness, 2, 202, 0, 100)));
    html.replace("%NIGHT_BRI_H%", String(map(oiler.nightBrightnessHigh, 2, 202, 0, 100)));
    
    server.send(200, "text/html", html);
}

void handleRoot() {
    resetWifiTimer();
    String html = htmlLanding;
    
    html.replace("%TIME%", getZurichTime());
    html.replace("%SATS%", String(gps.satellites.value()));
    
    String tempHeader = "--";
    if (oiler.isTempSensorConnected()) {
        tempHeader = String(oiler.getCurrentTempC(), 1);
    }
    html.replace("%TEMP%", tempHeader);
    
    html.replace("%TANK_LEVEL%", String(oiler.currentTankLevelMl, 0));
    html.replace("%TANK_CAP%", String(oiler.tankCapacityMl, 0));
    float pct = (oiler.tankCapacityMl > 0) ? (oiler.currentTankLevelMl / oiler.tankCapacityMl) * 100.0 : 0.0;
    html.replace("%TANK_PCT%", String(pct, 0));
    
    String tankColor = (pct <= oiler.tankWarningThresholdPercent) ? "#d32f2f" : "#ffc107";
    html.replace("%TANK_COLOR%", tankColor);
    
    html.replace("%TOTAL_DIST%", String(oiler.getTotalDistance(), 1));
    html.replace("%PUMP_COUNT%", String(oiler.getPumpCycles()));
    html.replace("%PROGRESS%", String(oiler.getCurrentProgress() * 100.0, 1));
    
    bool emerg = oiler.isEmergencyModeForced();
    html.replace("%EMERG_CLASS%", emerg ? "btn-danger" : "btn-sec");
    html.replace("%EMERG_STATUS%", emerg ? "ON" : "OFF");
    
    server.send(200, "text/html", html);
}

void handleSaveLED() {
    resetWifiTimer();
    webConsole.log("CMD: Save LED Settings");
    
    // Convert 0-100% back to 0-255
    if(server.hasArg("led_dim")) {
        int val = server.arg("led_dim").toInt();
        if (val < 0) val = 0; if (val > 100) val = 100;
        oiler.ledBrightnessDim = map(val, 0, 100, 2, 202);
    }
    if(server.hasArg("led_high")) {
        int val = server.arg("led_high").toInt();
        if (val < 0) val = 0; if (val > 100) val = 100;
        oiler.ledBrightnessHigh = map(val, 0, 100, 2, 202);
    }
    
    oiler.nightModeEnabled = server.hasArg("night_en");
    if(server.hasArg("night_start")) oiler.nightStartHour = server.arg("night_start").toInt();
    if(server.hasArg("night_end")) oiler.nightEndHour = server.arg("night_end").toInt();
    if(server.hasArg("night_bri")) {
        int val = server.arg("night_bri").toInt();
        if (val < 0) val = 0; if (val > 100) val = 100;
        oiler.nightBrightness = map(val, 0, 100, 2, 202);
    }
    if(server.hasArg("night_bri_h")) {
        int val = server.arg("night_bri_h").toInt();
        if (val < 0) val = 0; if (val > 100) val = 100;
        oiler.nightBrightnessHigh = map(val, 0, 100, 2, 202);
    }
    
    oiler.saveConfig();
    server.sendHeader("Location", "/led_settings");
    server.send(303);
}
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
void loop() {
    // Reset Watchdog
    esp_task_wdt_reset();

    // Handle Delayed Restart / Reset
    static int lastCountdown = 6;
    if (shouldRestart || shouldFactoryReset) {
        int remaining = 5 - ((millis() - restartTimer) / 1000);
        
        if (remaining < lastCountdown && remaining > 0) {
            String msg = "... " + String(remaining);
            webConsole.log(msg);
            Serial.println(msg);
            lastCountdown = remaining;
        }
        
        if (millis() - restartTimer > 5000) {
             if (shouldRestart) {
                 webConsole.log("RESTARTING NOW");
                 Serial.println("RESTARTING NOW");
                 delay(100);
                 ESP.restart();
             }
             if (shouldFactoryReset) {
                 oiler.performFactoryReset();
             }
        }
    } else {
        lastCountdown = 6;
    }

    // Read GPS Data
    while (gpsSerial.available() > 0) {
        char c = gpsSerial.read();
        gps.encode(c);
        // Optional: raw NMEA output
        // Serial.write(c);
    }

    float currentSpeed = gps.speed.isValid() ? gps.speed.kmph() : 0.0;

    // GPS filter: ignore data with poor signal quality
    // 1. Minimum 5 satellites
    // 2. HDOP < 5.0
    bool signalPoor = false;
    if (gps.location.isValid()) {
        if (gps.satellites.value() < 5 || gps.hdop.hdop() > 5.0) {
            signalPoor = true;
            currentSpeed = 0.0; // Force 0 speed
        }
    }

#ifdef GPS_DEBUG
    // GPS Debug Output
    static unsigned long lastGpsDebug = 0;
    if (millis() - lastGpsDebug > 2000) {
        lastGpsDebug = millis();
        
        String logMsg = String("GPS: Fix=") + (gps.location.isValid() ? "OK" : "NO") + 
                        ", Sats=" + String(gps.satellites.value()) + 
                        ", HDOP=" + String(gps.hdop.hdop(), 1) +
                        ", Spd=" + String(currentSpeed, 1);
        webConsole.log(logMsg);

        Serial.printf("GPS Status: Fix=%s, Sats=%d, Speed=%.1f km/h, Lat=%.6f, Lon=%.6f, HDOP=%.1f %s\n", 
            gps.location.isValid() ? "OK" : "NO", 
            gps.satellites.value(), 
            currentSpeed, // Show filtered speed
            gps.location.isValid() ? gps.location.lat() : 0.0,
            gps.location.isValid() ? gps.location.lng() : 0.0,
            gps.hdop.hdop(),
            signalPoor ? "[FILTERED]" : ""
        );
    }
#endif

    // Update Oiler Logic
    // Pass current time to Oiler (for Night Mode)
    if (gps.time.isValid() && gps.date.isValid()) {
        int h = oiler.calculateLocalHour(gps.time.hour(), gps.date.day(), gps.date.month(), gps.date.year());
        oiler.setCurrentHour(h);
    }
    
    // Update Oiler with GPS data
    // Ensure update is called at least every 1000ms to handle Emergency Mode (Forced or Auto)
    static unsigned long lastOilerUpdate = 0;
    bool gpsFresh = gps.location.isUpdated() || gps.speed.isUpdated();
    bool gpsValid = gps.location.isValid() && !signalPoor;
    bool gpsValidForUpdate = gpsFresh && gpsValid;
    double gpsLat = gpsValid ? gps.location.lat() : 0.0;
    double gpsLon = gpsValid ? gps.location.lng() : 0.0;
    
    if (gpsFresh || (millis() - lastOilerUpdate > 1000)) {
        // When called due to timeout, validity is false to enable signal-loss handling
        // Poor signal quality is treated as invalid
        oiler.update(currentSpeed, gpsLat, gpsLon, gpsValidForUpdate);
        lastOilerUpdate = millis();
    }
    
    // Run Oiler main loop (Button, LED, Bleeding)
    oiler.loop();
    
    // Run Aux Manager Loop
    auxManager.loop(oiler.getSmoothedSpeed(), oiler.lastTemp, oiler.isRainMode());
    
    // Pass Aux Status to Oiler for LED
    oiler.setAuxStatus(auxManager.getCurrentPwm(), (int)auxManager.getMode(), auxManager.isBoostActive());

#ifdef SD_LOGGING_ACTIVE
    if (millis() - lastLogTime > LOG_INTERVAL_MS) {
        writeLogLine("DATA");
        lastLogTime = millis();
    }
#endif

    // --- WiFi Management & Aux Toggle ---
    unsigned long currentMillis = millis();

    // 1. Button Requests (Handled by Oiler)
    if (oiler.checkWifiToggleRequest()) {
        if (!wifiActive) {
            // Activate WiFi
            // Set mode and channel to reduce disconnects
            WiFi.mode(WIFI_AP); 
            bool res = WiFi.softAP(AP_SSID, NULL, 1, 0, 4); // Channel 1, Hidden 0, MaxConn 4
            
            if (res) {
                IPAddress IP = WiFi.softAPIP();
                #ifdef GPS_DEBUG
                Serial.print("WiFi activated via Button. IP: ");
                Serial.println(IP);
                #endif
                dnsServer.start(53, "*", IP);
                server.begin();
                wifiActive = true;
                wifiStartTime = currentMillis;
            } else {
                #ifdef GPS_DEBUG
                Serial.println("WiFi Start Failed!");
                #endif
            }
        } else {
            // WiFi already active; extend timer
            wifiStartTime = currentMillis;
            webConsole.log("BTN: WiFi Timer Extended");
        }
    }

    if (oiler.checkAuxToggleRequest()) {
        auxManager.toggleManualOverride();
#ifdef GPS_DEBUG
        Serial.print("Aux Manual Override Toggled: ");
        Serial.println(auxManager.isManualOverrideActive() ? "ON" : "OFF");
#endif
    }

    // 2. Deactivation: Driving or Timeout
    if (wifiActive) {
        bool shouldStop = false;
        
        // Timeout Check
        if (currentMillis - wifiStartTime > WIFI_TIMEOUT) {
#ifdef GPS_DEBUG
            Serial.println("WiFi Timeout.");
#endif
            shouldStop = true;
        }
        
        // Speed Check (Auto-Off when driving)
        if (currentSpeed > MIN_SPEED_KMH) {
#ifdef GPS_DEBUG
            Serial.println("Driving detected -> WiFi off.");
#endif
            shouldStop = true;
        }

        if (shouldStop) {
            WiFi.softAPdisconnect(true);
            wifiActive = false;
        } else {
            // Handle Network Services
            dnsServer.processNextRequest();
            server.handleClient();
        }
    }
    
    // Pass WiFi status to Oiler (for LED indication)
    oiler.setWifiActive(wifiActive);

    delay(10);
}

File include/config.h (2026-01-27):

#ifndef CONFIG_H
#define CONFIG_H

#include <Arduino.h>

#define FIRMWARE_VERSION "2.0.4"
#define SD_LOGGING_ACTIVE      // SD logging enabled

// ==========================================
// 1. HARDWARE PINS (ESP32)
// ==========================================
#define PUMP_PIN            26   // MOSFET Gate - Safe Output
#define LED_PIN             32   // WS2812B Data
#define GPS_RX_PIN          16   // GPS RX -> ESP TX (RX2)
#define GPS_TX_PIN          27   // GPS TX -> ESP RX (Alternative to 17)
#define BUTTON_PIN          0    // Handlebar Button (Boot Button)
#define BOOT_BUTTON_PIN     0    // Onboard Boot Button (GPIO 0)
#define AUX_PIN             17   // Aux Power Relay / Heated Grips
#define TEMP_SENSOR_PIN     4    // DS18B20 Data Line
#define IMU_SDA             21   // BNO085 I2C SDA
#define IMU_SCL             22   // BNO085 I2C SCL

#ifdef SD_LOGGING_ACTIVE
    #define SD_CS_PIN       5
    #define SD_MOSI_PIN     23
    #define SD_MISO_PIN     19
    #define SD_CLK_PIN      18
#endif

// ==========================================
// 2. PUMP CONTROL & PWM
// ==========================================
#define PUMP_ON             HIGH
#define PUMP_OFF            LOW
#define PUMP_USE_PWM        true    // Enable Soft-Start/Stop
#define PUMP_PWM_FREQ       5000    // 5 kHz (Safe for most solenoids)
#define PUMP_PWM_CHANNEL    0       // LEDC Channel
#define PUMP_PWM_RESOLUTION 8       // 8-bit (0-255)
#define PUMP_RAMP_UP_MS     12      // Soft-Start Duration
#define PUMP_RAMP_DOWN_MS   12      // Soft-Stop Duration
#define PUMP_SAFETY_CUTOFF_MS 30000 // HARD LIMIT: Max continuous run

// ==========================================
// 3. CORE OILING LOGIC & SPEEDS
// ==========================================
// Standard Oiling
#define PULSE_DURATION_MS   55      // Time the pump stays OPEN
#define PAUSE_DURATION_MS   2000    // Time between multiple pulses
#define MIN_SPEED_KMH       7.0     // Minimum speed to trigger oiling
#define MIN_ODOMETER_SPEED_KMH 2.0  // Count distance above this speed

// Limits
#define MAX_SPEED_KMH       250.0   // Plausibility Ceiling

// ==========================================
// 4. SPECIAL MODES CONFIGURATION
// ==========================================
// Chain Flush Mode
#define FLUSH_DEFAULT_EVENTS    15    // Total cycles
#define FLUSH_DEFAULT_PULSES    2     // Pulses per cycle
#define FLUSH_DEFAULT_INTERVAL_SEC 5 // Seconds between cycles
#define FLUSH_PRESS_COUNT       4     // Button clicks to activate? (See code logic)

// Offroad Mode
#define OFFROAD_INTERVAL_MIN_DEFAULT 5 // Minutes between cycles
#define OFFROAD_PULSES_DEFAULT       3
#define OFFROAD_PRESS_COUNT          3 // Button clicks (See code logic)

// Bleeding (Maintenance)
#define BLEEDING_DURATION_MS    25000 // Total run time (25s)
#define BLEEDING_PULSE_MS       60    // Pulse length (Needs to match/exceed ramp)
#define BLEEDING_PAUSE_MS       320   // Cycle pause

// Startup Delay
#define STARTUP_DELAY_METERS_DEFAULT 250.0 // Distance before first oiling allowed

// ==========================================
// 5. TIMINGS & TIMEOUTS
// ==========================================
#define WIFI_TIMEOUT_MS         300000   // 5 Min: Disable AP
#define RAIN_MODE_AUTO_OFF_MS   1800000  // 30 Min: Auto-reset Rain Mode
#define SAVE_INTERVAL_MS        300000   // 5 Min: Save progress to NVS
#define STANDSTILL_SAVE_MS      120000   // 2 Min: Save if stopped
#define EMERGENCY_TIMEOUT_MS    180000   // 3 Min: Switch to Emergency Mode if NO GPS
#define TEMP_UPDATE_INTERVAL_MS 60000    // 1 Min: Read Temperature

// Button Interactions
#define BUTTON_SEQUENCE_TIMEOUT_MS 600   // Time to wait after last click before processing
#define WIFI_PRESS_COUNT        5        // 5 Clicks: WiFi Config
#define AUX_HOLD_MS             2000     // Hold >2s: Toggle Aux
#define FACTORY_RESET_PRESS_MS  10000    // Hold >10s at boot

// ==========================================
// 6. LED / UI CONFIGURATION
// ==========================================
#define NUM_LEDS                2
#define LED_BRIGHTNESS_DIM      64    // Standard status
#define LED_BRIGHTNESS_HIGH     153   // Active event

// Animation Timings (ms)
#define LED_PERIOD_OILING       1000
#define LED_PERIOD_EMERGENCY    1500
#define LED_PERIOD_WIFI         1500
#define LED_PERIOD_GPS          1000
#define LED_BLINK_FAST          100
#define LED_BLINK_TANK          2000
#define LED_PERIOD_FLUSH        500
#define LED_WIFI_SHOW_DURATION  10000

// ==========================================
// 7. SYSTEM & DEBUG
// ==========================================
#define GPS_BAUD                9600
#define AP_SSID                 "ChainJuicer"
#define GPS_DEBUG                 // Uncomment for Serial Debug

#ifdef SD_LOGGING_ACTIVE
    #define LOG_FILE_PREFIX     "/log_"
    #define LOG_INTERVAL_MS     1000
#endif
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

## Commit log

2025-11-26 Implement early oiling feature with 95% distance trigger to prevent double oiling during speed changes
    [Oiler.cpp]
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2025-11-27 Add support for ESP32-S3 and enhance web interface functionality
    - Updated platformio.ini to include configuration for ESP32-S3 board.
    - Modified HTML footer in main.cpp to improve layout and remove unnecessary onclick confirmations for refill and reset actions.
    - Added new handler functions for resetting statistics and refilling the tank.
    - Improved server routing to handle common connectivity checks and filter out unnecessary requests.
    [main.cpp]
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2025-11-29 Enhance GPS functionality and user experience with new features
    - Implemented smart GPS filtering to ignore ghost speeds based on HDOP and satellite count.
    - Added a startup delay of 10 seconds to prevent pump malfunctions during initialization.
    - Updated LED behavior for oiling indication and WiFi status, including pulsing effects.
    - Enhanced web interface to allow LED brightness settings in percentage.
    - Introduced a case button for additional user input.
    - Refactored code for better readability and maintainability.
    [Oiler.cpp, Oiler.h, config.h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]
2025-11-30 Refine brightness limits for LED settings to ensure values remain within a safe range (2-202)
2025-11-30 Update LED brightness comments and adjust minimum speed thresholds for oiling functionality
2025-12-01 Update README and help documentation; remove unused case button and reset rain mode on startup
    [Oiler.cpp, config.h]
2025-12-01 Add configurable timeouts and intervals for various operations
    - Introduced new timeout and interval constants in config.h for WiFi, rain mode auto-off, save intervals, and emergency oiling.
    - Updated Oiler.cpp to utilize the new constants for improved readability and maintainability.
    - Refactored time checks in the loop and update methods to use defined constants instead of hardcoded values.
    - Enhanced debug logging for better traceability during operation.
2025-12-01 Refactor HTML footer handling to prevent malformed output by removing redundant closing table tag
    [main.cpp]
2025-12-01 Translate hardware section and button functions in README from German to English for improved accessibility.
2025-12-02 Add BOM section to README with ESP32 WROOM 32e details and link
2025-12-02 Fix typo in BOM section of README for ESP32 WROOM 32e description
2025-12-02 Fix link formatting in BOM section of README for ESP32 WROOM 32e
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2025-12-02 Remove startup delay from configuration and related code for improved pump initialization
2025-12-10 Refactor pump control logic to use defined constants for better readability and maintainability
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2025-12-13 Update hardware pin definitions for consistency and correct GPS baud rate
    [config.h]
2025-12-13 Update hardware pin definitions for consistency and add GPS baud rate comment
2025-12-13 Fix BUTTON_PIN definition to correct pin number
    [config.h]
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2025-12-13 Refactor HTML page handling by moving header, footer, and help content to separate header file; update LED update logic for emergency mode
2025-12-14 Enhance help documentation: clarify Rain and Emergency modes, improve button function descriptions, and standardize terminology
2025-12-14 Remove lemon SVG icon handling for favicon and return 404 for missing icon
    [main.cpp]
2025-12-14 Update README and Oiler functionality for improved LED status indications and WiFi management
2025-12-14 Add safety cutoff and factory reset functionality to Oiler class
    [Oiler.cpp, Oiler.h, config.h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]
2025-12-14 Implement factory reset functionality in Oiler class
    [Oiler.cpp, Oiler.h, main.cpp]
2025-12-14 Update hardware pin definitions in config.h for correct mapping
    [config.h]
2025-12-14 Update README and Oiler class for improved features and LED indications; remove obsolete help and interface files
2025-12-14 Update safety cutoff duration for pump and display satellite count in HTML response
2025-12-15 Refactor pump control logic: replace hardcoded LOW with PUMP_OFF constant and update README and config.h for clarity on PUMP_INVERTED usage.
    [Oiler.cpp, config.h]
2025-12-21 Add detailed wiring schematic for ChainJuicer Light, including power supply, pump control, GPS module, handlebar button, status LED, and SD card module connections.
2025-12-24 Implement PWM control for pump with soft-start/stop functionality and add configuration options
2025-12-24 Implement temperature compensation for pump control, including dynamic pulse and pause adjustments based on viscosity changes, and update related configuration settings.
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2025-12-25 Update temperature pulse and pause timings for improved performance across temperature ranges
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2025-12-27 Refactor temperature compensation model to simplify configuration and enhance logging; update web interface for oil viscosity selection and temperature display.
2025-12-27 Refactor temperature compensation settings saving and update temperature display method for accuracy
2025-12-27 Refactor temperature compensation logic to simplify calculations and remove lookup table; update default temperature settings in initialization
2025-12-27 Refactor temperature compensation logic to use Arrhenius equation for viscosity calculation; adjust compensation aggressiveness based on oil type
2025-12-27 Add temperature display to HTML output and improve Oiler update logic for GPS data
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2025-12-27 Refactor temperature compensation logic to use minimum pulse duration and update compensation aggressiveness based on real-world calibration
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2025-12-28 Update README and configuration for improved LED timings and pump behavior in Bleeding Mode
2025-12-28 Update drops per ml and drops per pulse for improved calibration accuracy
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2025-12-28 Add IMU integration with calibration and safety checks; update Oiler and main logic
2025-12-28 Refactor Oiler class by removing unused Turbo Mode functionality; update README with IMU feature details and enhance c_cpp_properties for library paths
2025-12-28 Refactor code structure for improved readability and maintainability
    [125ml measurement cube.3mf, 22mm handlebar housing for button 12mm and LED 5mm.3mf]
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2025-12-29 Add safety check to prevent oiling while stationary in loop function
    [Oiler.cpp]
2025-12-29 Enhance web installer UI with improved button styles and debug information for loading errors
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2025-12-29 Add optional SD card logging feature with detailed data format and wiring instructions
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2025-12-29 Rename Turbo Mode to Chain Flush Mode and update related logic and configuration
2025-12-29 Update crash detection logic to trigger at a lean angle > 70 degrees and implement crash latch functionality
    [ImuHandler.cpp, ImuHandler.h, Oiler.cpp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]
2025-12-29 Add Aux Port Manager functionality and configuration options for smart power and heated grips
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2025-12-29 Update README with detailed MOSFET wiring instructions and LED status codes for Aux Port
2025-12-29 Implement feature X to enhance user experience and optimize performance
    [ChainOiler_housings.3mf]
2025-12-30 Refactor grip settings to include temperature offset and update HTML configuration for improved user input options
2025-12-30 Add Smart Power description to HTML configuration and update visibility logic for heated grips
2025-12-30 Update HTML configuration for heated grips: rename fields for clarity and remove example calculation
2025-12-30 Update grip settings to include start temperature and adjust HTML configuration for user input
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2025-12-31 Remove Rain Mode checkbox handling and update temperature sensor status display in settings
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2025-12-31 Update README: correct Aux Power status description for clarity
2025-12-31 Fix resistor value in README to 220Ω for pump control during ESP32 boot
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2026-01-01 Enhance IMU features: add turn safety logic, crash detection, and garage guard; update documentation and logging for better diagnostics
    [ImuHandler.cpp, ImuHandler.h, Oiler.cpp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]
2026-01-01 Enhance Oiler and main logic: track oil consumption during bleeding, prevent accidental WiFi deactivation, and improve logging for diagnostics
    [Oiler.cpp, Oiler.h, main.cpp]
2026-01-01 Implement delayed restart and factory reset functionality with countdown notifications
    [main.cpp]
2026-01-01 Refactor restart and factory reset responses to use 303 redirect and improve countdown logging
    [main.cpp]
2026-01-01 Refactor restart and factory reset endpoints to improve response handling and update flags to volatile
    [main.cpp]
2026-01-01 Improve update handling: provide detailed success/failure messages and implement a delayed reboot with a refresh notification
    [main.cpp]
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2026-01-01 Refactor Oiler class: implement pump state machine and remove factory reset check from setup
    [Oiler.cpp, Oiler.h, main.cpp]
2026-01-01 Fix button color for Firmware Update link in maintenance HTML
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2026-01-01 Adjust pump duty cycle to start at ~50% and prevent whining during operation
    [Oiler.cpp]
2026-01-02 Enhance heated grips logic with boost timer reset and effective start time handling
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2026-01-02 Update night mode settings and enhance factory reset logic
    [Oiler.cpp]
2026-01-02 Enhance factory reset logic to ensure previous session is closed and add delay for stability
    [Oiler.cpp]
2026-01-04 Refactor IMU handling: rename isParked to isStationary, update calibration methods, and enhance stability checks
    [ImuHandler.cpp, ImuHandler.h, Oiler.cpp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]
2026-01-04 Enhance IMU initialization with bus recovery mechanism and timeout to improve stability
    [ImuHandler.cpp]
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2026-01-05 Fix version dates and enhance IMU calibration info
    Updated release notes with corrected version dates and improved IMU calibration process details.
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2026-01-05 Add watchdog reset during firmware update process
    [main.cpp]
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2026-01-07 Fix namespace handling in saveConfig and saveProgress methods
    [Oiler.cpp]
2026-01-07 Fix namespace handling by closing it after loading configuration in Oiler::begin
    [Oiler.cpp]
2026-01-13 Fix configuration and initialization issues
    - Updated TEMP_SENSOR_PIN to GPIO 2 and changed TEMP_UPDATE_INTERVAL_MS to 60 seconds to prevent button blocking.
    - Modified IMU initialization to first attempt connection at address 0x4B, with a fallback to the default address 0x4A.
    - Ensured pump is turned OFF immediately during initialization in both Oiler and main setup functions to prevent glitches.
    [ImuHandler.cpp, Oiler.cpp, config.h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]
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2026-01-14 Fix temperature sensor pin configuration to correct wiring issue
    [config.h]
2026-01-14 Update temperature sensor update interval to 60 seconds to prevent button blockade
    [config.h]
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2026-01-14 Refactor emergency mode logic and enhance GPS handling; reset WiFi timer on relevant commands
    [Oiler.cpp, main.cpp]
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
